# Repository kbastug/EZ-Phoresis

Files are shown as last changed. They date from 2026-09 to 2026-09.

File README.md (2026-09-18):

# EZ-Phoresis™

**EZ-Phoresis™™** is a 3D-printable gel electrophoresis system designed to provide an accessible, reproducible platform for research and educational laboratory use.

This repository contains the files and documentation required to print, assemble, and operate the EZ-Phoresis™ system.

Citation
If EZ-Phoresis™ is used in published research, please cite the associated publication:

[Citation to be added after publication]

Until publication, please cite the repository as:

Bastug, K. (2026). EZ-Phoresis: A low cost, 3D-Printable Gel Electrophoresis System (Version 1.x). NIH 3D. https://doi.org/10.60705/3DPX/23670.1

## Repository Contents

### `STL_files/`

Ready-to-print STL files for the 3D-printed components of the EZ-Phoresis™ system.

### `F3D_files/`

Editable F3D design files for users who wish to inspect or modify the design.

### `STP_files/`

Editable STP design files for users who wish to inspect or modify the design.

### `EZ-Phoresis_Assembly_Instructions/`

Printing, assembly, and operating instructions for the EZ-Phoresis™ system.

### `EZ-Phoresis Bill of Materials/`

Bill of materials listing the non-printed components required for assembly.

### `License/`

Licenseing information

### `Safety/`

Important safety information for building and operating this system.

## Getting Started

To construct an EZ-Phoresis™ system:

1. Download the required STL files from the `STL/` folder.
2. Review the printing recommendations in the `EZ-Phoresis_Assembly_Instructions/` folder.
3. Obtain the required non-printed components listed in the bill of materials.
4. Follow the assembly instructions to construct the electrophoresis system.
5. Review the safety information in `SAFETY.md` before connecting or operating the device.
6. Follow the operating instructions provided with the design.

Users wishing to modify the design should use the editable files rather than modifying the STL meshes whenever possible.

## NIH 3D

The printable EZ-Phoresis™ models are also available through NIH 3D:

**[NIH 3D link to be added]**

GitHub serves as the primary repository for the complete EZ-Phoresis™ design package, including editable CAD files, instructions, bill of materials, safety information, and version history.

## License

© 2026 Kristen Bastug.

The design files, CAD files, STL files, drawings, assembly instructions, documentation, and other copyrightable materials associated with **EZ-Phoresis™** are licensed under the Creative Commons Attribution-NonCommercial-ShareAlike 4.0 International License (CC BY-NC-SA 4.0).

You may copy, modify, share, and adapt these materials for non-commercial purposes, subject to the terms of CC BY-NC-SA 4.0.

Commercial uses are not licensed under CC BY-NC-SA 4.0. Parties interested in commercial use or separate commercial licensing should contact Kristen Bastug at [kristen.bastug@gmail.com].

Modified versions that are shared must identify that modifications were made and must be distributed under the same license, as required by CC BY-NC-SA 4.0.

Official license:
https://creativecommons.org/licenses/by-nc-sa/4.0/

Legal code:
https://creativecommons.org/licenses/by-nc-sa/4.0/legalcode.en

See `LICENSE.txt` for additional information and the complete license terms.

## Attribution

When sharing, adapting, presenting, or otherwise publicly using the EZ-Phoresis™ design, please provide appropriate attribution.

Suggested attribution:

**Bastug K. EZ-Phoresis™: a 3D-printable gel electrophoresis system. 2026.**

Once the associated manuscript and/or persistent repository identifier is available, please cite:

**[Full manuscript citation or DOI to be added]**

## Safety Warning

> **WARNING:** EZ-Phoresis™ is an electrically powered gel electrophoresis device. Electrophoresis power supplies can generate voltages capable of causing electrical shock, serious injury, or death if the system is improperly constructed or operated.

These design schematics, files, and assembly guides are provided **“AS IS” without warranties of any kind, express or implied. Users construct and operate this device at their own risk.**

Always:

* operate the system with the protective lid fully attached;
* never touch the electrophoresis buffer, electrodes, wiring, or conductive components while the device is energized;
* disconnect the power supply before opening, adjusting, cleaning, or servicing the device;
* inspect the device and electrical connections before use; and
* follow applicable institutional laboratory and electrical safety requirements.

Additional safety information is provided in `SAFETY.md`.

EZ-Phoresis™ is intended for **research and educational use** and has not been validated or approved for clinical diagnostic use.

## Disclaimer

Users are responsible for determining whether EZ-Phoresis™ is appropriate for their intended application and for ensuring that fabrication, assembly, electrical connections, and operation comply with applicable institutional requirements, laboratory safety practices, and local regulations.

To the extent permitted by applicable law, the designer and contributors assume no liability for injury, property damage, experimental loss, data loss, or other damages resulting from the fabrication, modification, assembly, operation, or use of EZ-Phoresis™.

## Modifications and Contributions

Users may modify EZ-Phoresis™ for noncommercial purposes in accordance with the CC BY-NC-SA 4.0 license.

If modified versions are publicly shared, they should:

* clearly identify that the design has been modified;
* identify the original EZ-Phoresis™ design;
* provide appropriate attribution; and
* be shared under CC BY-NC-SA 4.0.

Feedback, bug reports, documentation improvements, and proposed design improvements may be submitted through the GitHub repository.

## Versioning

Design changes should be associated with a version number so that publications and experimental reports can identify the specific EZ-Phoresis™ configuration used.

Current version:

**EZ-Phoresis™ v1.0**

Release date:

**[Month 2026]**

## Citation

If EZ-Phoresis™ is used in published research, please cite the associated publication:

**[Citation to be added after publication]**

Until publication, please cite the repository as:

**Bastug K. EZ-Phoresis™: a 3D-printable gel electrophoresis system. Version 1.0. 2026. [repository DOI/link].**

## Contact

For questions regarding the design, research use, or commercial licensing:

**Kristen Bastug**
[contact email]

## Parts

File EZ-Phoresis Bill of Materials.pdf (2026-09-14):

EZ-Phoresis Bill of Materials

Component | Amount Needed | Cost per unit (USD) | Cost (USD) | Source of materials

Hardware
Female Banana Socket, non-solder | 2 (One red, one black) | 0.76 | 7.59 for 10 units | Link (https://www.amazon.com/Lzzvibo-4mm-Banana-Plug-Connector/dp/B0DFZ1SK2N?nsdOptOutParam=true)
22 gauge stainless steel wire | 50 cm | 0.06 | 8.99 for 262 feet | Link (https://www.amazon.com/Stainless-Jewelry-Making-Bailing-Trapping/dp/B0BXPJDTTJ?sp_csd=d2lkZ2V0TmFtZT1zcF9hdGY)
PTFE Teflon tubing, 2mm ID x 4mm OD | 14 cm | 1.86 | 7.99 for 5 feet | Link (https://www.amazon.com/Teflon-tubing-Filament-Printer-Tech/dp/B073RDFTDV)
Moldable silicone putty, white and circular | About 1 meter of ¼ to ½ cm diameter | 0.33 -1.34 | 15.75 for 1in x 18in | Link (https://www.amazon.com/900-Moldable-Silicone-Putty-Circular/dp/B0DY2NWD7Q?sp_csd=d2lkZ2V0TmFtZT1zcF9hdGY)

3D Printing
Component A (Lid): PLA filament, 1.75mm | 73g | 1.17 | 15.99 for 1000g | Any
Component B (Base): PETG filament, 1.75 mm | 367g | 5.87 | 15.99 for 1000g | Link (https://www.amazon.com/IEMAI-PETG-Filament-Transmittance-Transparent/dp/B0CMLFLPF1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)
Component C (Gel Comb): PLA filament, 1.75mm | 7g | 0.11 | 15.99 for 1000g | Any
Component D (Tray, Double): PLA filament, 1.75mm | 77g | 1.14 | 15.99 for 1000g | Any
Component E (Tray, Triple): PLA filament, 1.75mm | 76g | 0.99 | 15.99 for 1000g | Any

Optional
M-M Banana plug test leads, to connect EZ-Phoresis to commercial power supply. Users should check compatibility between the type of banana plug connection needed for their particular power supply | 2 | 6.00 | 11.99 for 2 units | Link (https://www.amazon.com/Banana-Silicone-Multimeter-Electrical-Testing/dp/B0F53F4L2G?s=industrial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)
Total | | 12.29-19.30

Other Supplies
- Wire cutters
- Pliers (straight or needle-nosed)
- Flat kitchen knife
- 3D-Printer
- Scissors

Note: Costs and availability of materials will vary for users depending on location. The supplies listed were tested with the EZ-Phoresis system, with demonstrated feasibility. Users may choose to substitute equivalent items from other brands depending on local availability.

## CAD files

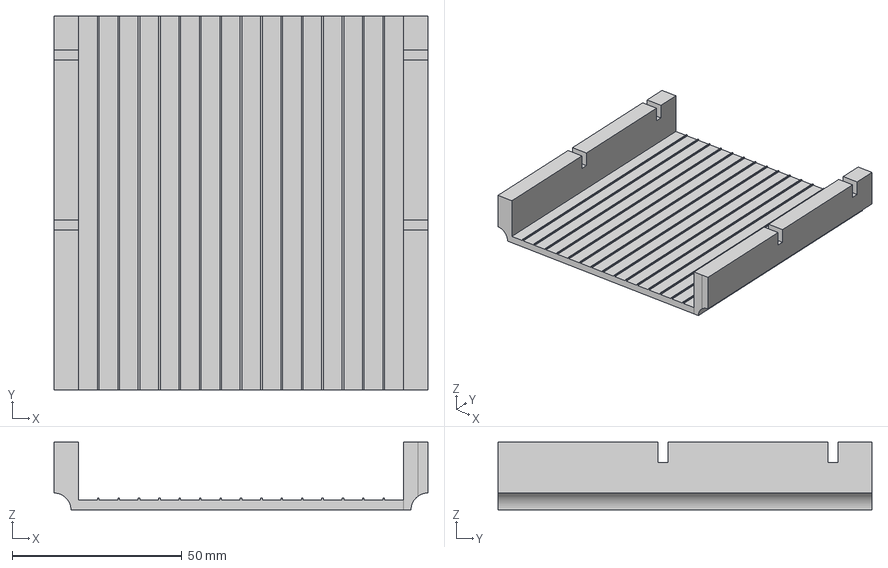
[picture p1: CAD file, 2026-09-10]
STP_files/Tray_double_EZ-Phoresis.step
110.0 x 110.0 x 20.0 mm

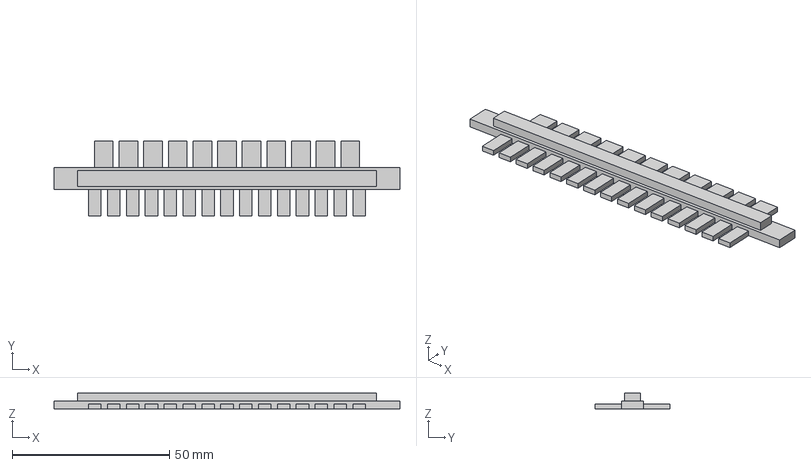
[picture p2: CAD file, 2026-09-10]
STP_files/Comb_EZ-Phoresis.step
110.0 x 24.0 x 5.00 mm

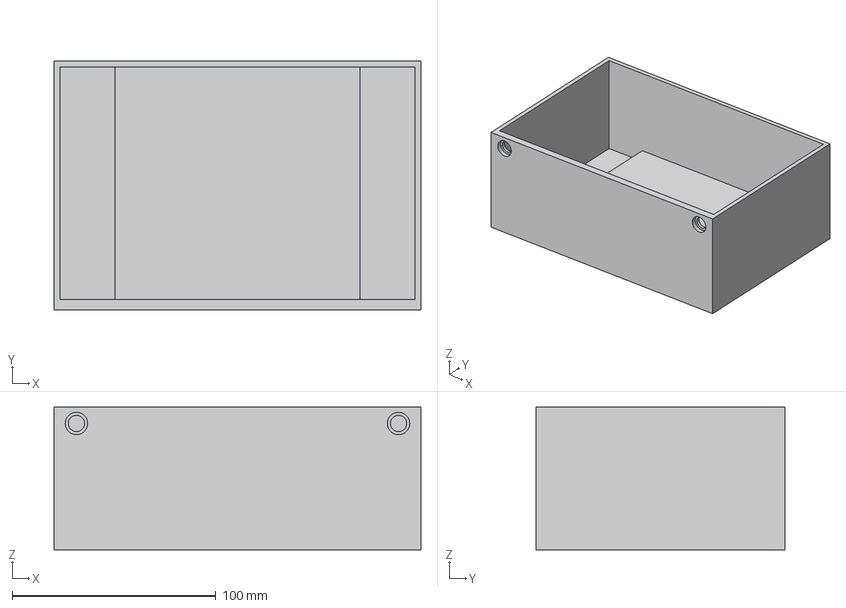
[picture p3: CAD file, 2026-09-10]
STP_files/Base_EZ-Phoresis.step
180.0 x 122.0 x 70.0 mm

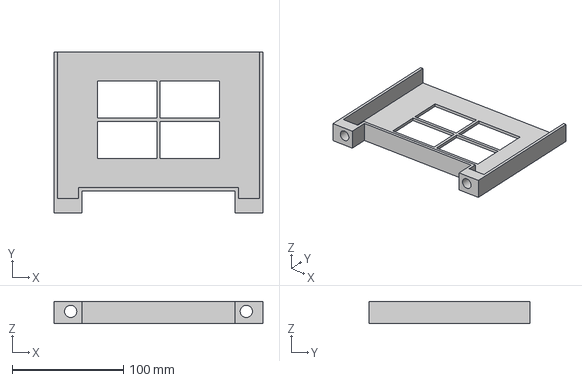
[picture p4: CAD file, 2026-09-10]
STP_files/Lid_EZ-Phoresis.step
188.0 x 145.0 x 20.0 mm

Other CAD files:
STP_files/Tray_triple_EZ-Phoresis.step
F3D_files/Base_EZ-Phoresis.f3d
F3D_files/Comb_EZ-Phoresis.f3d
F3D_files/Lid_EZ-Phoresis.f3d
F3D_files/Tray_double_EZ-Phoresis.f3d
F3D_files/Tray_triple_EZ-Phoresis.f3d
STL_files/Base_EZ-Phoresis.stl
STL_files/Comb_EZ-Phoresis.stl
STL_files/Lid_EZ-Phoresis.stl
STL_files/Tray_double_EZ-Phoresis.stl
STL_files/Tray_triple_EZ-Phoresis.stl

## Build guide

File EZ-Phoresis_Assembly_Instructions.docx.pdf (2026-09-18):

# EZ-Phoresis™

# Assembly Instructions

Version 1 | September 10, 2026

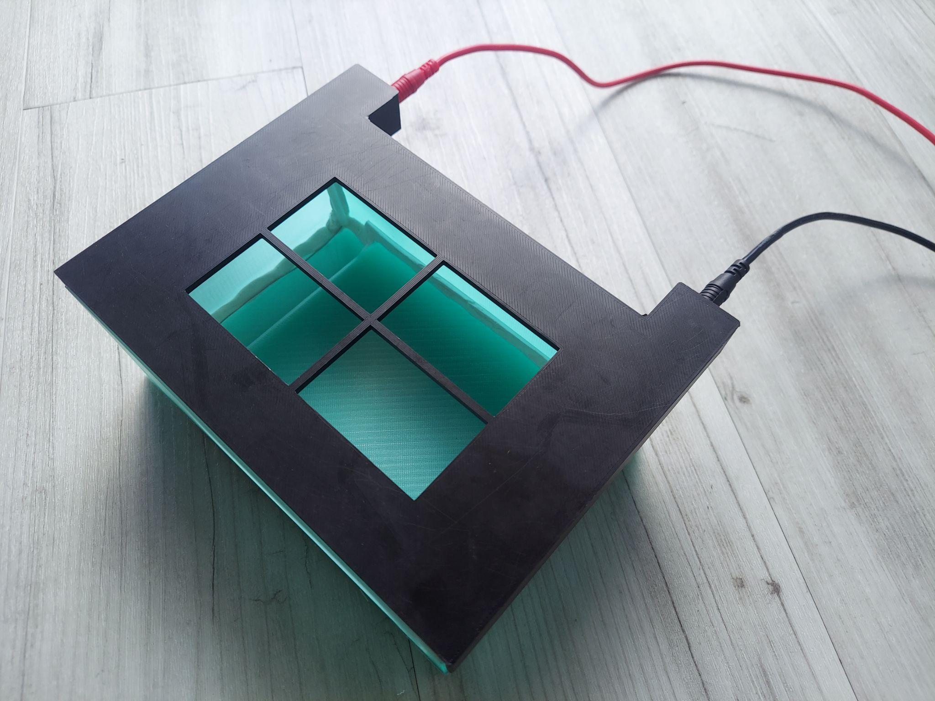
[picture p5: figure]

A compact, 3D-printable gel electrophoresis system designed for research and educational use.

This guide covers printing, component preparation, electrical connector assembly, wire placement, sealing, and final lid installation.

Before you begin
- Review the safety information on the next page.
- Confirm that all printed parts, hardware, wire, tubing, and silicone putty are available.
- Work on a clean, dry surface with the electrophoresis power supply disconnected.

If you used or fabricated the EZ-Phoresis design, please cite the following:
Bastug, K. (2026). EZ-Phoresis: a 3D-printable gel electrophoresis system (Version 1.0). https://doi.org/10.60705/3DPX/23670.1

For the design development and validation study, the associated manuscript citation will be added when available.

EZ-Phoresis™ | 1

## Safety Warning and Disclaimer

### ELECTRICAL HAZARD

EZ-Phoresis™ is an electrically powered gel electrophoresis device. Electrophoresis power supplies can generate voltages capable of causing electrical shock, serious injury, or death. Users must understand the electrical and laboratory hazards associated with electrophoresis before constructing or operating this device.

Required safety practices
- Always operate the device with the protective lid fully installed.
- Never touch the electrophoresis buffer, electrodes, conductive components, or internal wiring while the system is energized.
- Disconnect the power supply before removing the lid or making any adjustment to the device.
- Inspect the device, electrodes, wiring, connectors, and lid before each use.
- Do not operate a damaged, leaking, improperly assembled, or electrically compromised device.
- Use only a suitable electrophoresis power supply and appropriately rated electrical components.
- Follow applicable institutional laboratory safety procedures and electrical safety requirements.
- Appropriate supervision and training are required.

Disclaimer of liability
These design files, schematics, assembly guides, and associated materials are provided “AS IS,” without warranties of any kind, express or implied.

Users construct, modify, assemble, and operate this device at their own risk and are responsible for determining whether the device is appropriate and safe for their intended application.

To the extent permitted by applicable law, the designer and contributors assume no liability for injury, property damage, data loss, experimental loss, or other damages arising from fabrication, modification, assembly, operation, or use of the device.

EZ-Phoresis™ is intended for research and educational use and has not been validated or approved for clinical diagnostic use.

© 2026 Kristen Bastug.

The design files, CAD files, STL files, drawings, assembly instructions, documentation, and other copyrightable materials associated with EZ-Phoresis are licensed under the Creative Commons Attribution-NonCommercial-ShareAlike 4.0 International License (CC BY-NC-SA 4.0). You may copy, modify, share, and adapt these materials for non-commercial purposes, subject to the terms of CC BY-NC-SA 4.0.

Commercial uses are not licensed under CC BY-NC-SA 4.0. Parties interested in commercial use or separate commercial licensing should contact Kristen Bastug at kristen.bastug@gmail.com.

Modified versions that are shared must identify that modifications were made and must be distributed under the same license, as required by CC BY-NC-SA 4.0.

Official license: https://creativecommons.org/licenses/by-nc-sa/4.0/

Legal code: https://creativecommons.org/licenses/by-nc-sa/4.0/legalcode.en

## Overview & 3D Printing Guidance

This document provides instructions to assemble the EZ-Phoresis™ system. Ensure that you have all supplies listed in the Bill of Materials before beginning. This guide assumes a baseline understanding of 3D printing and gel electrophoresis.

Required tools: scissors, wire cutters, pliers (straight or needle-nose), and a standard kitchen butter knife.

Standard printing specifications (use unless otherwise specified)
- Structural mode
- 0.2 mm layer height
- 2 perimeters
- 20% infill
- No structural supports
- Brim recommended

STL files for all components are intended to be distributed through the project GitHub repository and the NIH 3D Print Exchange. Add the final links before publication.

Component | File name | Description | Material | Additional specifications
A | Lid_EZ-Phoresis.stl | Gel electrophoresis lid | PLA | Standard settings
B | Base_EZ-Phoresis.stl | Gel electrophoresis base; requires further assembly | PETG | 5 perimeters; ≥90% infill
C | Comb_EZ-Phoresis.stl | Double-sided comb: 15 wells (4 × 1.5 × 8.5 mm) or 11 wells (6 × 1.5 × 8.5 mm) | PLA or PETG | Standard settings
D | Tray_double_EZ-Phoresis.stl | Gel-casting tray with attachment points for up to two combs | PLA or PETG | ≥90% infill
E | Tray_triple_EZ-Phoresis.stl | Gel-casting tray with attachment points for up to three combs | PLA or PETG | ≥90% infill

Filament selection
- Any color may be used, but a light-colored or translucent filament may make bands easier to see during electrophoresis.
- The system was tested using PETG for the base and PLA for the other components.
- PLA may be sufficient for the base, but may be less durable over time and may have poorer water impermeability.

## Materials for Base Assembly

The following materials are required to assemble Component B (the electrophoresis base).

Image | Description | Quantity | Preparation / notes
| PTFE (Teflon) tubing | 4 pieces, 4.5 cm each | 2 mm ID × 4 mm OD
| 22-gauge stainless-steel wire | 2 pieces, 25 cm each | See electrode material note below

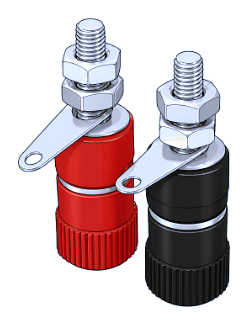
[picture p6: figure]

| Female banana socket, solder-free | 1 red and 1 black | Remove the ring terminal; it is not needed
| Moldable silicone putty, white | As needed | Cut into thin strips, approximately ¼ cm wide

Electrode material note. Platinum wire is standard in commercially available electrophoresis systems and may also be used with EZ-Phoresis™. Stainless steel is more widely available and substantially less expensive, but will require more frequent replacement because of anodic dissolution during electrolysis.

## Assembly Instructions — Base

1 Prepare the silicone putty. Peel sections from the roll and divide each section lengthwise into quarters to create thin, long strips.

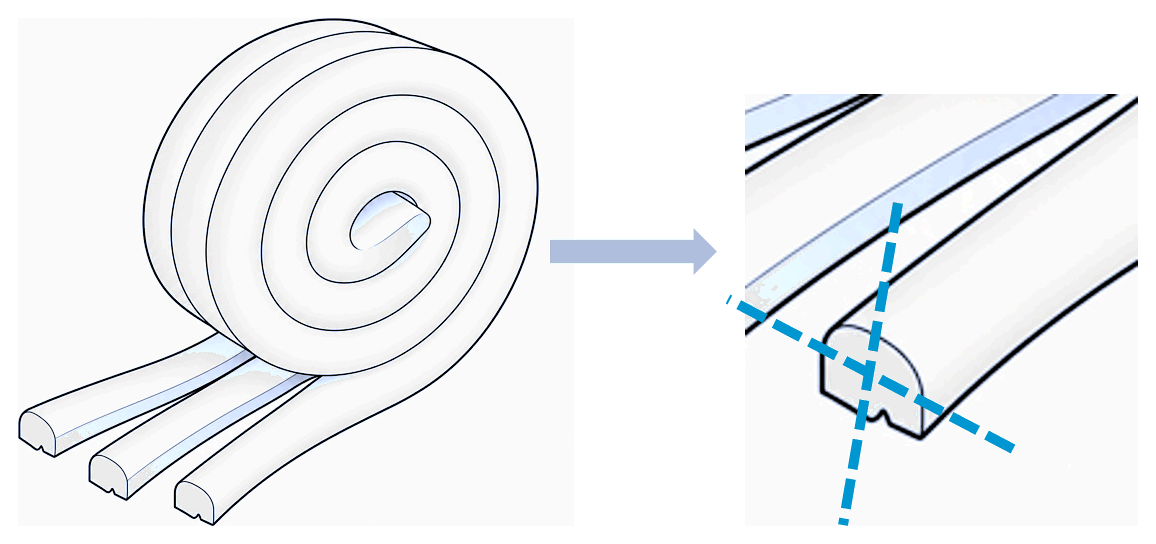
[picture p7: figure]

Cut the silicone putty into narrow, continuousstrips.

2 Sealthe inside corners and seams. Press silicone putty into the locations shown*. This improves resistance to liquid leakage and can be removed and re-applied as needed. Putty does not dry out when exposed to the air.

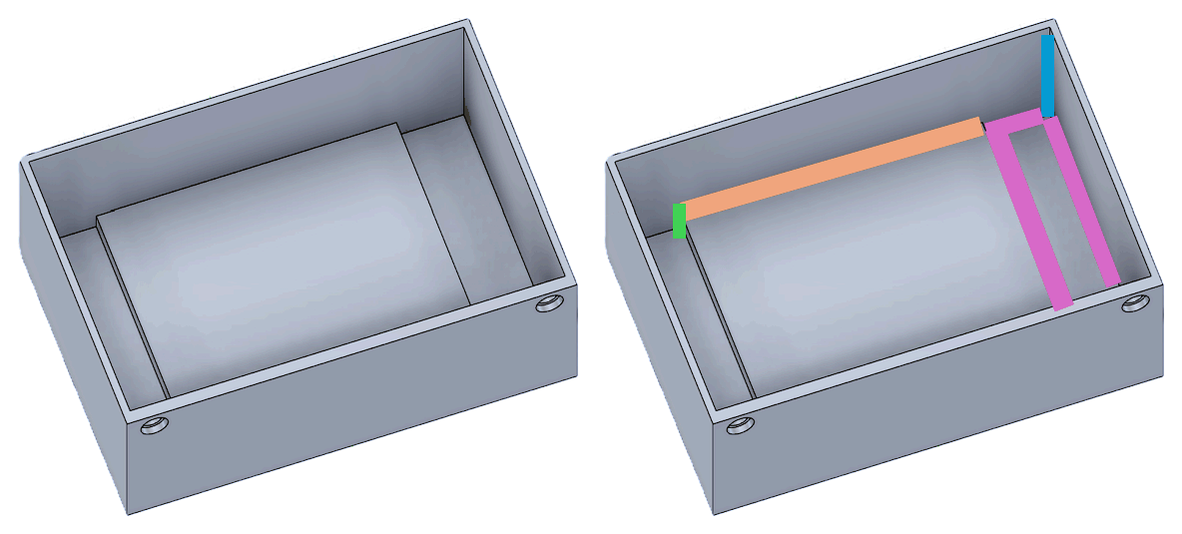
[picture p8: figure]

*Apply putty to the four vertical corners, tray-supportseams, base perimetersections, and interior verticalsections.

- Blue: four inside vertical corners
- Orange: two long tray-support seams
- Pink: four sides on each end (8 strips total)
- Green: four interior vertical sections

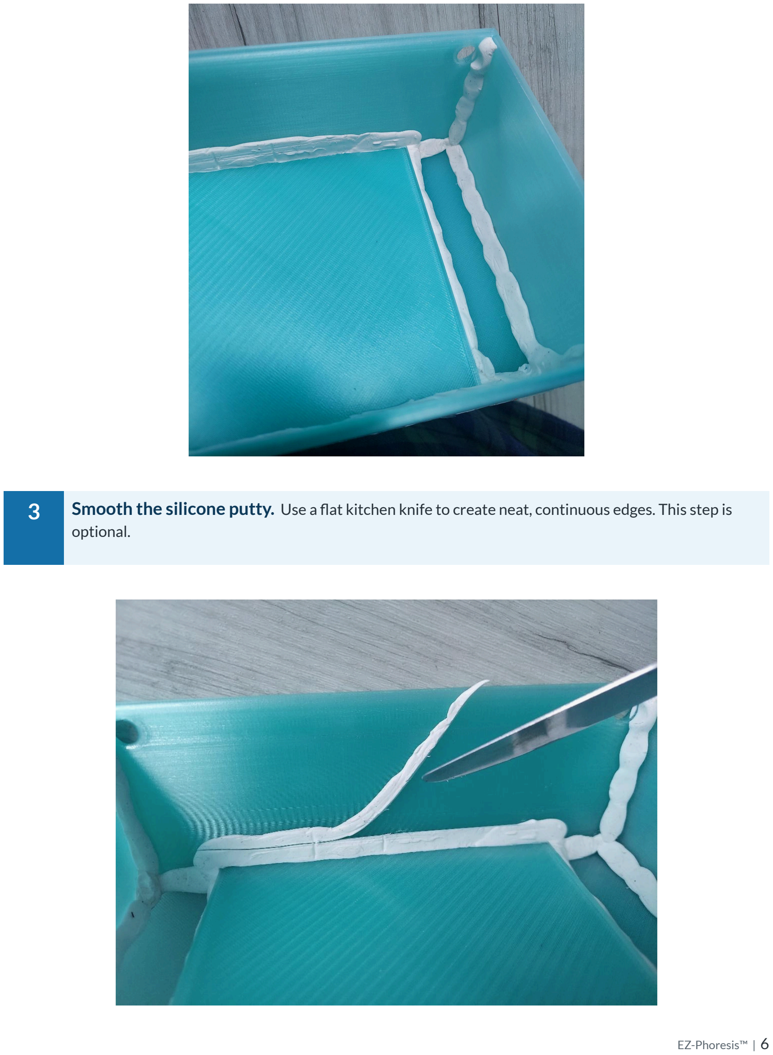
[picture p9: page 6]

3 Smooth the silicone putty. Use a flat kitchen knife to create neat, continuous edges. This step is optional.

4 Installthe red and black banana sockets. Attach the sockets to the two holes in the base. Use the red socket at one end and the black socket at the opposite end, as shown.

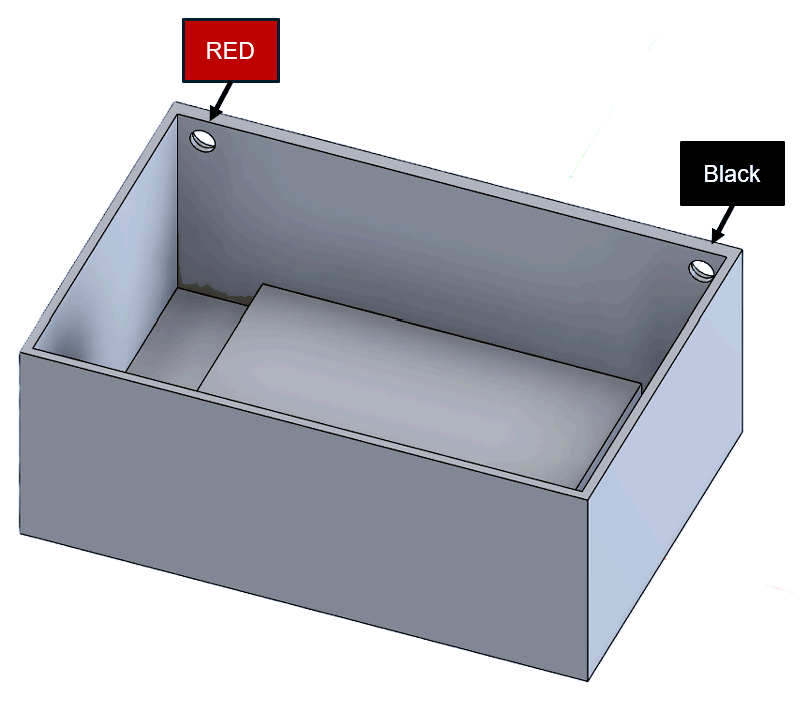
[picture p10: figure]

## Assembly Instructions — Electrical Connections

5 Loosely assemble each banana socket. Insert the socket through the wall and assemble the washer and nuts on the inside. Leave the inner nuts loose enough to receive the stainless-steel wire. The outer red/black connector receives the power-supply lead.

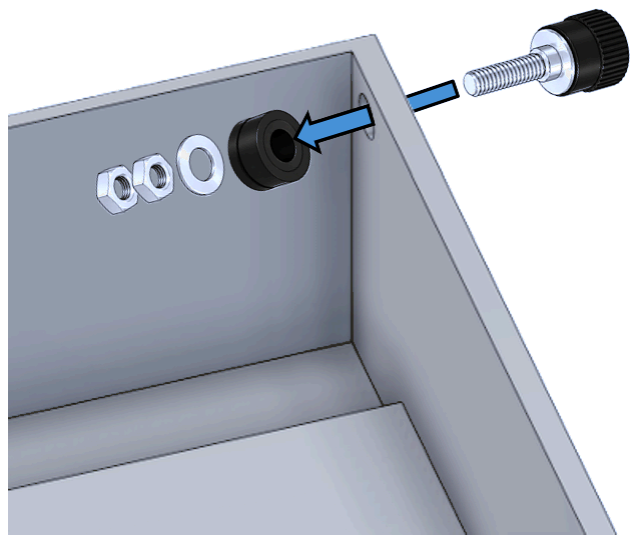
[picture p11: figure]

Exploded view of the solder-free banana socket assembly.

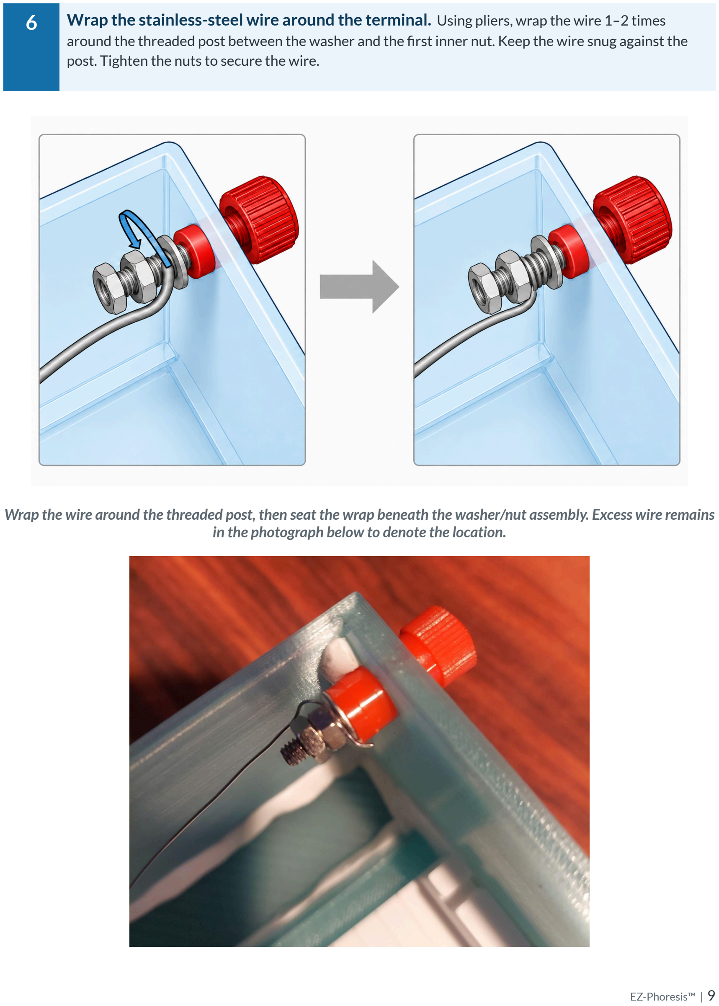
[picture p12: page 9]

6 Wrap the stainless-steel wire around the terminal. Using pliers, wrap the wire 1–2 times
around the threaded post between the washer and the first inner nut. Keep the wire snug against the post. Tighten the nuts to secure the wire.

Wrap the wire around the threaded post, then seat the wrap beneath the washer/nut assembly. Excess wire remains in the photograph below to denote the location.

## Assembly Instructions — Shape the Electrodes

7 Insulate and make the first bend. Slide one 4.5 cm piece of PTFE tubing onto the wire. At Point B, make a 90° bend so the wire runs parallel to the short edge of the box.

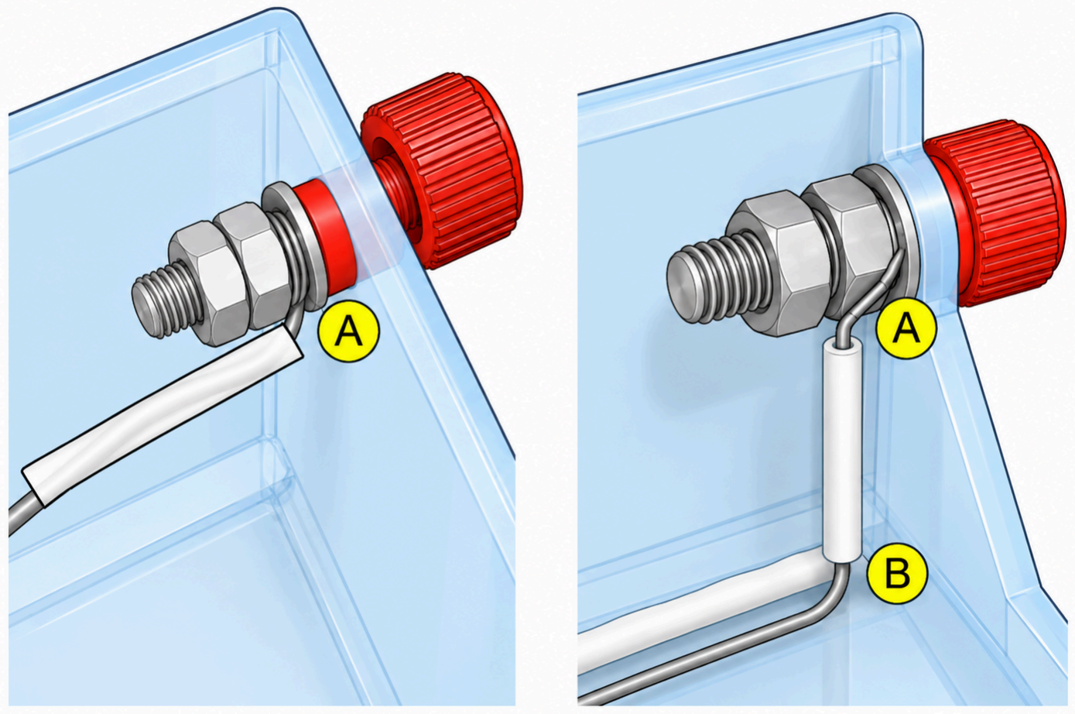
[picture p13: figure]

Point A marksthe terminal connection; Point B marksthe first 90° bend.

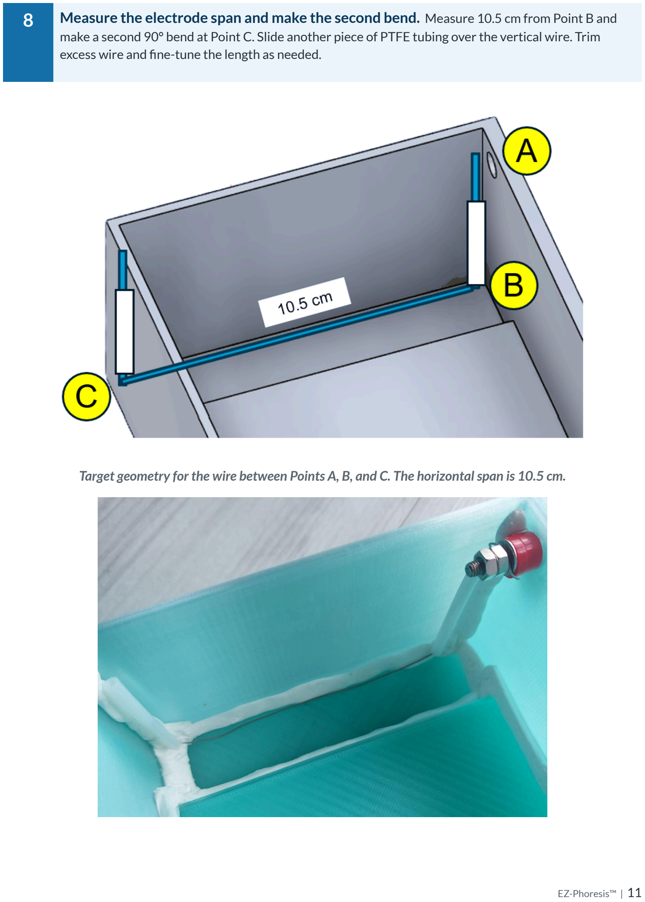
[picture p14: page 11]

### 8 Measure the electrode span and make the second bend. Measure 10.5 cm from Point B and

make a second 90° bend at Point C. Slide another piece of PTFE tubing over the vertical wire. Trim excess wire and fine-tune the length as needed.

Target geometry for the wire between Points A, B, and C. The horizontalspan is 10.5 cm.

## Assembly Instructions — Secure & Finish

9 Secure the insulated wire. Use light pressure to seat the PTFE tubing into the silicone putty. The exposed stainless-steel wire may also be pressed gently into the putty for stability. Trim any excess wire at the terminal as needed.

Note: It is important that the stainless steel wire is as straight as possible, to ensure a uniform electric field

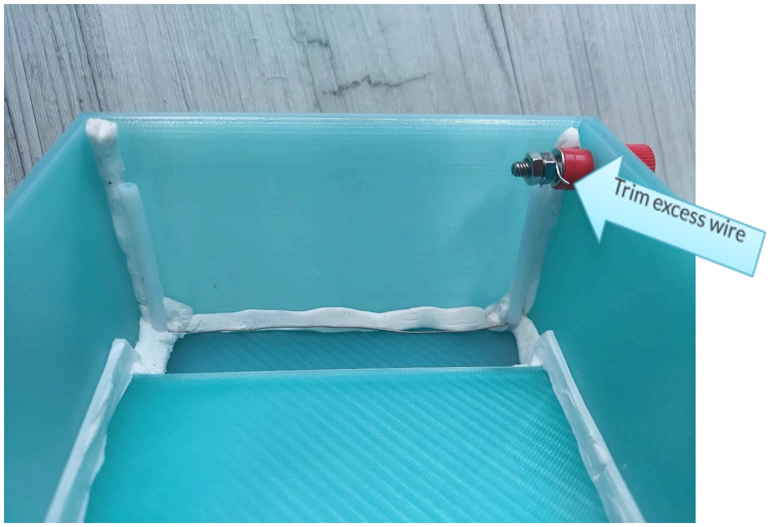
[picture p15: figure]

Completed electrode positioned and supported by the silicone putty.

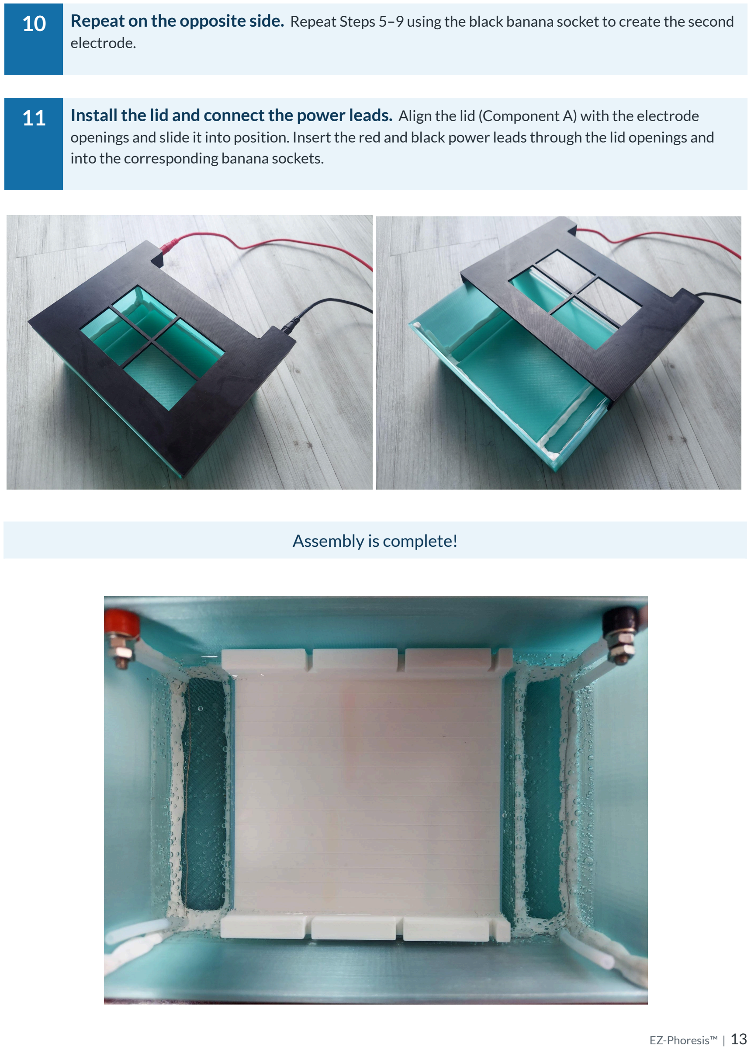
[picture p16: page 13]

10 Repeat on the opposite side. Repeat Steps 5–9 using the black banana socket to create the second electrode.

11 Installthe lid and connectthe power leads. Align the lid (Component A) with the electrode openings and slide it into position. Insert the red and black power leads through the lid openings and into the corresponding banana sockets.

Assembly is complete!
